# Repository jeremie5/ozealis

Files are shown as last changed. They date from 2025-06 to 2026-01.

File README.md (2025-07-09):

# Ozealis – The $75 Experimental CPAP Simulator

> ⚠️ **NOT A MEDICAL DEVICE.** Experimental use only.  
> **→ See full legal disclaimer below.**

---

WARNING: This project is in pre-prototype / design phase. Nothing is tested yet.
However, you’re welcome to follow, watch, or help out. Contributions and issues are welcome!

---

## 💡 What Is Ozealis?

Ozealis is a fully open-source, modular platform for exploring low-cost, user-driven air-pressure systems. It was created by necessity — for those of us who can’t afford to wait for diagnosis, approval, or overpriced medical devices.

This project is not a product, nor a substitute for professional care. It is a tool for personal experimentation, educational insight, and collaborative innovation.

Because sleep should be safe, and safety should be accessible.

---

## 🔧 Features

- ✅ PTC fuse protection on all power paths
- ✅ Reverse polarity protection via MOSFET (no diode drop)
- ✅ Optional power outage alarm via buzzer and capacitor-based UPS
- ✅ DC5525 input (11V–30V) — compatible with laptop bricks & power stations
- ✅ Differential pressure sensing via physical baffle (not RPM guesswork)
- ✅ Pre/Post humidity & temperature sensing
- ✅ Modular accessory port (USB-A + I²C) for:
  - Heated hose module  
  - Humidifier module  
- ✅ App-controlled via Bluetooth
- ✅ Compatible with $6 standard CPAP hoses
- ✅ No proprietary parts, no DRM
- ✅ Fully 3D-printable enclosure with FDM-optimized geometry

---

## 📷 Photos & Demos

Coming soon. This section will include:

- High-resolution photos  
- Assembly walk-throughs  
- App UI screenshots  
- Demo video showing pressure response & noise levels  

---

## 📦 Getting Started

### 🛠️ Build It Yourself

**Documentation coming soon.** For now, refer to:

- `hardware/` – Schematics, PCB layout, and BoM  
- `firmware/` – ESP32 firmware and config  
- `case/` – STL and STEP files for enclosure (PC + TPU)

Assembly requires:

- Basic soldering skills  
- A 3D printer with 0.4–0.6 mm nozzle  

---

## 📱 App & Data Logging

- Connect via WiFi to view real-time pressure graphs  
- Export logs in JSON or CSV  
- Tune pressure ramp profiles & buzzer thresholds  
- OTA firmware updates planned  

---

## 🛡️ Safety Systems

Ozealis includes multiple built-in protections:

- 🧯 Overcurrent protection on all input/output rails  
- 🔔 Power-loss alarm wakes user with buzzer  
- 🌡️ Thermal cutoff disables output at unsafe temps  
- 💨 Airflow anomaly detection via differential pressure monitoring  

> This level of visibility is **absent in many commercial machines**.

---

## 📄 License

This project is licensed under the **Creative Commons Attribution-NonCommercial 4.0 International (CC BY-NC 4.0)**.

Commercial use (manufacturing, distribution, resale) requires a separate license.  
**Contact:** `team@ozealis.org`

See `LICENSE.md` for full terms.

---

## 🚫 Not a Medical Device

Ozealis is **not approved** by Health Canada, the FDA, or any regulatory agency.  
It is an airflow simulation platform intended for **research and experimental purposes only**.

> No claims are made regarding the treatment, cure, or prevention of sleep apnea or any other condition.

---

## 🤝 Contribute

Pull requests welcome! Areas to contribute:

- App UI & UX polish  
- Log export improvements  
- Pressure tuning curves  
- Testing with accessories (heated hoses, passive humidifiers)  

Fork → improve → PR 💜

---

## 🗺️ Roadmap

- ✅ Full BoM and build guide  
- ✅ App-based tuning UI  
- ✅ Web configurator for real-time control  
- 🎥 YouTube demo + sound comparison  
- 🌍 Translations (FR, EN, ES)

---

**CRITICAL DISCLAIMER — READ BEFORE BUILDING OR USING OZEALIS**  
>   
> 1. **No Medical Device.** Ozealis has **NOT** been reviewed or approved by any
>    regulatory body (FDA, Health Canada, EU MDR, etc.). It is an
>    **experimental air-pressure simulator** provided solely for research,
>    educational and personal *non-commercial* use.  
> 2. **No Professional Advice.** All documentation is for informational
>    purposes only and does **not** constitute medical, engineering, or legal
>    advice. Consult qualified professionals before any practical use.  
> 3. **AS-IS, NO WARRANTIES.** The files, firmware and hardware designs are
>    provided **“AS IS,” WITH ALL FAULTS, WITHOUT WARRANTIES** of any kind,
>    express or implied, including but not limited to merchantability,
>    fitness for a particular purpose and non-infringement.  
> 4. **Assumption of Risk.** You assume **all risks** arising from loading,
>    building, testing or using Ozealis. You are responsible for validating
>    safety, performance and regulatory compliance of any assembly.  
> 5. **Indemnity.** To the maximum extent permitted by law, you **agree to
>    indemnify and hold harmless** Shopiro Ltd. and contributors from any
>    claim, liability or expense (including legal fees) arising from your
>    use, reproduction, or distribution of these materials.  
> 6. **Limitation of Liability.** In no event shall Shopiro Ltd. or
>    contributors be liable for **any indirect, special, incidental or
>    consequential damages** (including personal injury or death) or for an
>    amount exceeding **USD 10**, even if advised of the possibility.  
> 7. **Governing Law & Venue.** These terms are governed by the laws of
>    Québec, Canada, and you consent to exclusive jurisdiction of its courts.  
>
> **By cloning, downloading, or using any part of this repository you
> acknowledge that you have read, understand, and agree to ALL of the above.**

---

Made with urgency, necessity, and care in Canada 🇨🇦  
Because breathing shouldn't require a credit check.

**Ozealis™ is a trademark of Shopiro Ltd.**

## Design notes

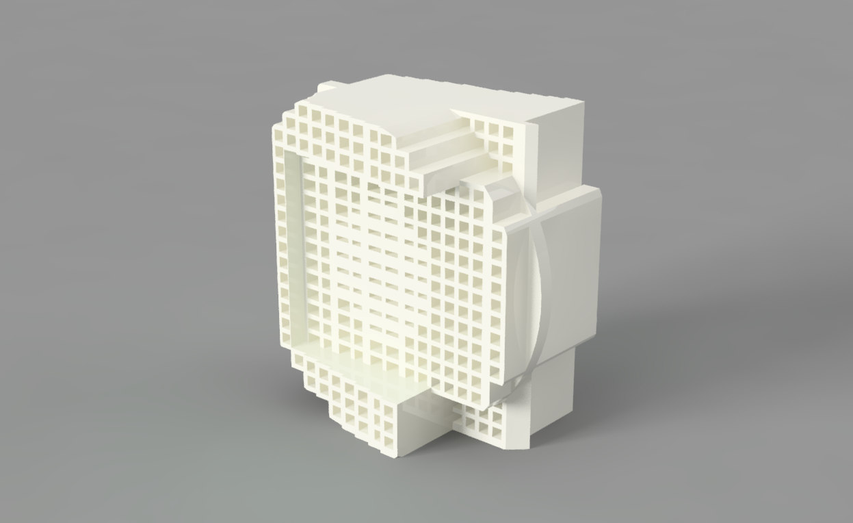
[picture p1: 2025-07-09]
pictures/muffler.png

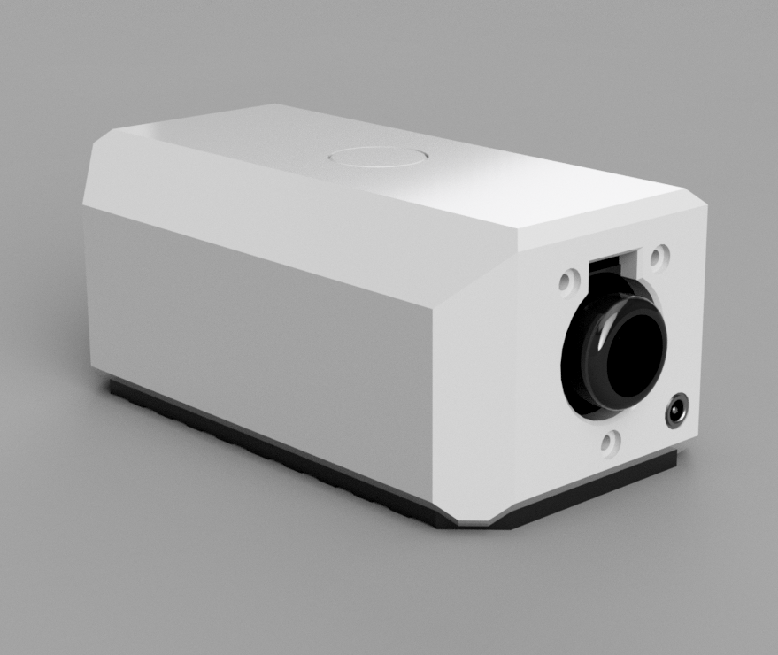
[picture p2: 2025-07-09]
pictures/body.png

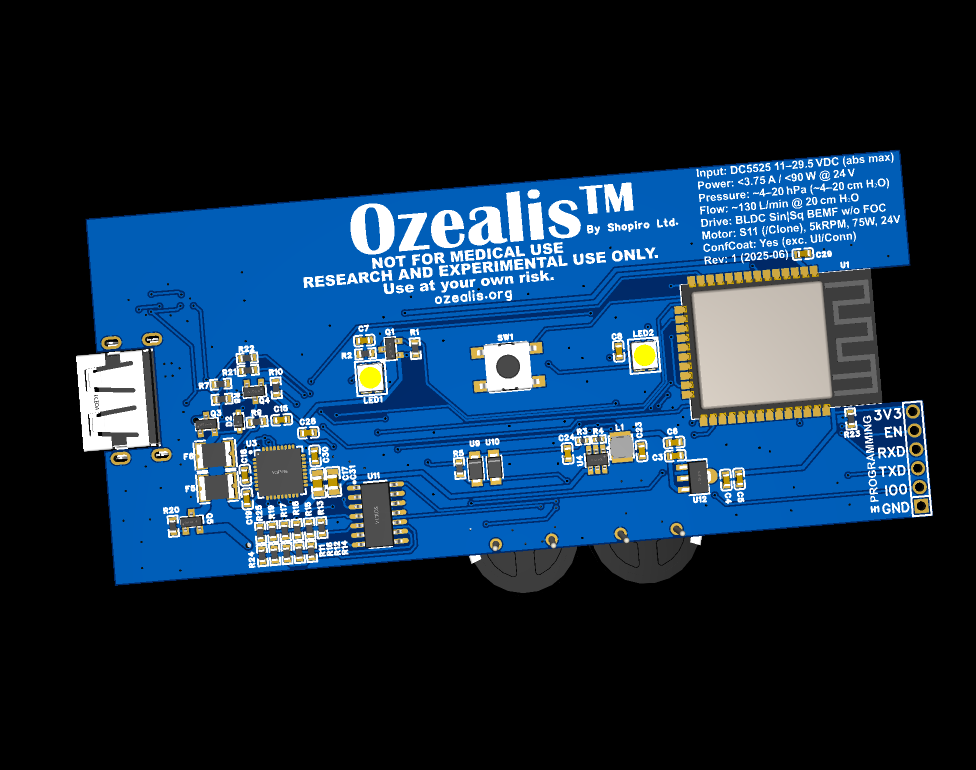
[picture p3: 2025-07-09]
pictures/pcb.png

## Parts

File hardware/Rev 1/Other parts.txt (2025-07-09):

Motor: https://s.click.aliexpress.com/e/_on0QQjY
LPS22HBTR (if unavailable for PCBA): https://s.click.aliexpress.com/e/_omS8MRu
Barrel connector: https://s.click.aliexpress.com/e/_on21ypG

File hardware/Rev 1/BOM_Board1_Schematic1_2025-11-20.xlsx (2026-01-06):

No. | Quantity | Comment | Designator | Footprint | Value | Manufacturer Part | Manufacturer | Supplier Part | Supplier
1 | 1 | 3kHz | BUZZER1 | BUZ-SMD_L9.6-W9.6-LS10.0-R | 3kHz | FUET-9650B-3V | FUET(福声科技) | C391032 | LCSC
2 | 12 | 100nF | C3,C4,C7,C8,C9,C11,C15,C22,C23,C27,C28,C33 | C0603 | 100nF | CC0603KRX7R9BB104 | YAGEO(国巨) | C14663 | LCSC
3 | 5 | 1uF | C5,C6,C10,C12,C29 | C0603 | 1uF | CL10A105KB8NNNC | SAMSUNG(三星) | C15849 | LCSC
4 | 2 | 10uF | C17,C31 | C0805 | 10uF | GRM21BR61H106KE43L | muRata(村田) | C440198 | LCSC
5 | 1 | 10uF | C24 | C0603 | 10uF | TCC0603X5R106M6R3CT | CCTC(三环) | C380318 | LCSC
6 | 2 | 6.3V10000uF | C25,C26 | PolCap_16x25mm | 6.3V10000uF
7 | 1 | 470nF | C30 | C0603 | 470nF | CL10B474KA8NNNC | SAMSUNG(三星) | C1623 | LCSC
8 | 1 | 100uF | C32 | CAP-SMD_BD6.3-L6.6-W6.6-LS7.4-FD | 100uF | RVT100UF35V67RV0034 | KNSCHA(科尼盛) | C2836442 | LCSC
9 | 1 | 10nF | C34 | C0603 | 10nF | 0603B103K500NT | FH(风华) | C57112 | LCSC
10 | 1 | HCZZ0469-2 | CN1 | CONN-SMD_2P-P2.00_HCZZ0469-2 |  | HCZZ0469-2 | HC(虹成电子) | C7433663 | LCSC
11 | 1 | BZT52C10S | D2 | SOD-323_L1.7-W1.3-LS2.6-RD |  | BZT52C10S | 宏嘉诚 | C19077446 | LCSC
12 | 2 | SMD1812-200C-30V | F5,F6 | F1812 |  | SMD1812-200C-30V | BNstar(比诺星) | C2760293 | LCSC
13 | 1 | 2.54-1x6P直针 | H1 | HDR-TH_6P-P2.54-V-M-1 |  | 2.54-1x6P直针 | BOOMELE(博穆精密) | C37208 | LCSC
14 | 1 | 3.3uH | L1 | IND-SMD_L3.0-W3.0_FNR30XXS | 3.3uH | FNR3015S3R3MT | cjiang(长江微电) | C167749 | LCSC
15 | 3 | BLM21PG221SN1D | L2,L3,L4 | L0805 |  | BLM21PG221SN1D | muRata(村田) | C85840 | LCSC
16 | 2 | SK6812MINI-B-012 | LED1,LED2 | LED-SMD_4P-L3.5-W3.5-R-SK6812MINI |  | SK6812MINI-B-012 | 欧思科光电 | C5183448 | LCSC
17 | 1 | BSS138 | Q1 | SOT-23-3_L2.9-W1.3-P1.90-LS2.4-BR-1 |  | BSS138 | KUU | C3015220 | LCSC
18 | 1 | IRLML6344 | Q2 | SOT-23-3_L3.0-W1.7-P0.95-LS2.9-BR |  | IRLML6344 | Hottech(合科泰) | C5364313 | LCSC
19 | 1 | CJ2305 | Q3 | SOT-23-3_L2.9-W1.3-P1.90-LS2.4-BR |  | CJ2305 | CJ(江苏长电/长晶) | C8549 | LCSC
20 | 1 | MMBT3904(RANGE:100-300) | Q4 | SOT-23-3_L2.9-W1.3-P1.90-LS2.4-BR |  | MMBT3904(RANGE:100-300) | CJ(江苏长电/长晶) | C20526 | LCSC
21 | 1 | AO3401A | Q5 | SOT-23_L2.9-W1.3-P1.90-LS2.4-BR |  | AO3401A | UMW(友台半导体) | C347476 | LCSC
22 | 5 | 10kΩ | R1,R2,R11,R12,R13 | R0603 | 10kΩ | RC0603FR-0710KL | YAGEO(国巨) | C98220 | LCSC
23 | 1 | 118kΩ | R3 | R0402 | 118kΩ | RC0402FR-07118KL | YAGEO(国巨) | C295873 | LCSC
24 | 1 | 22.1kΩ | R4 | R0402 | 22.1kΩ | RMC040222.1K1%N | Tyohm(幸亚电阻) | C325588 | LCSC
25 | 1 | 2.2Ω | R5 | R0603 | 2.2Ω | FRC0603J2R2TS | FOJAN(富捷) | C2930032 | LCSC
26 | 17 | 10kΩ | R6,R7,R8,R9,R20,R23,R24,R26,R27,R28,R29,R30,R31,R32,R33,R34,R35 | R0603 | 10kΩ | FRC0603J103 TS | FOJAN(富捷) | C2930027 | LCSC
27 | 1 | 1kΩ | R10 | R0603 | 1kΩ | 0603WAF1001T5E | UNI-ROYAL(厚声) | C21190 | LCSC
28 | 7 | 100kΩ | R14,R15,R16,R17,R18,R19,R25 | R0603 | 100kΩ | 0603WAF1003T5E | UNI-ROYAL(厚声) | C25803 | LCSC
29 | 2 | 100Ω | R21,R22 | R0603 | 100Ω | 0603WAF1000T5E | UNI-ROYAL(厚声) | C22775 | LCSC
30 | 1 | B3FS-1000P | SW1 | KEY-SMD_4P-L6.0-W6.3-P4.50-LS8.0 |  | B3FS-1000P | OMRON(欧姆龙) | C271750 | LCSC
31 | 1 | ESP32-WROOM-32E-N8 | U1 | WIFI-SMD_ESP32-WROOM-32E |  | ESP32-WROOM-32E-N8 | ESPRESSIF(乐鑫) | C701342 | LCSC
32 | 1 | DRV8313RHHR | U3 | VQFN-36_L6.0-W6.0-P0.50-TL-EP |  | DRV8313RHHR | TI(德州仪器) | C165154 | LCSC
33 | 1 | LMR54406DBVR | U4 | SOT-23-6_L2.9-W1.6-P0.95-LS2.8-BR |  | LMR54406DBVR | TI(德州仪器) | C5219316 | LCSC
34 | 2 | LPS22HBTR | U5,U6 | HLGA-10L_LPS22HBTR |  | LPS22HBTR | ST(意法半导体) | C94049 | LCSC
35 | 1 | AHT20 | U7 | SENSOR-SMD_L3.0-W3.0-P1.00-BR |  | AHT20 | 广州奥松 | C2757850 | LCSC
36 | 2 | SD103AWL | U9,U10 | SOD-123FL_L2.8-W1.9-LS3.7-RD |  | SD103AWL | GOODWORK(固得沃克) | C22399516 | LCSC
37 | 1 | LM339 | U11 | SOIC-14_L8.7-W3.9-P1.27-LS6.0-BL |  | LM339 | JSMSEMI(杰盛微) | C5456631 | LCSC
38 | 1 | AMS1117-3.3(XBLW) SOT-89 | U12 | SOT-89-3_L4.5-W2.5-P1.50-LS4.2-BR |  | AMS1117-3.3(XBLW) SOT-89 | XBLW(芯伯乐) | C18723569 | LCSC
39 | 1 | AFB10-S06LCA-00 | U13 | FPC-SMD_6P-P1.00_AFB10-S6LCA-00 |  | AFB10-S06LCA-00 | JS(钜硕电子) | C7499263 | LCSC
40 | 1 | U-A-24DS-W-1 | USB2 | USB-A-SMD_U-A-24DS-W-1. |  | U-A-24DS-W-1 | 韩国韩荣 | C530628 | LCSC

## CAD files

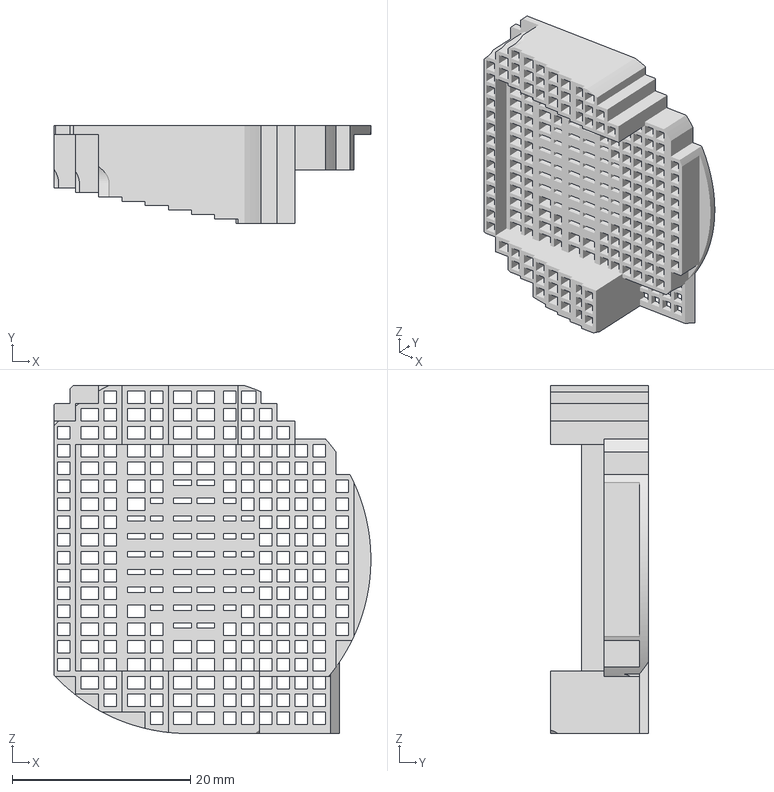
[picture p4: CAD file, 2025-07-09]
hardware/Rev 1/Parts/InletResonator2.3mf
35.5 x 11.0 x 39.0 mm

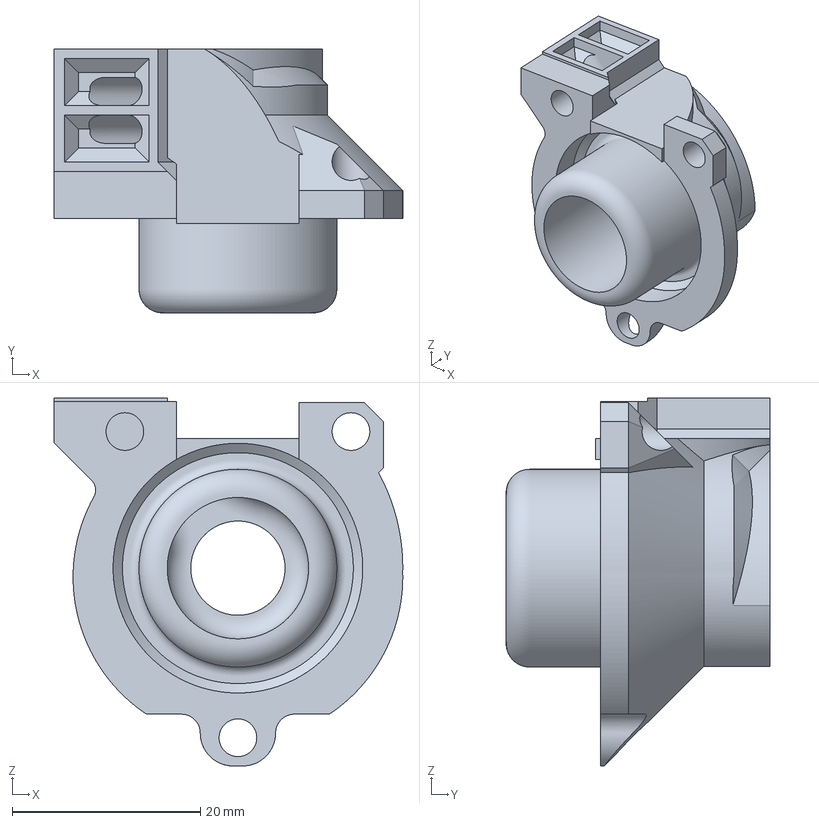
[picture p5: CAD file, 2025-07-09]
hardware/Rev 1/Parts/HoseConnector.3mf
37.0 x 28.0 x 39.1 mm

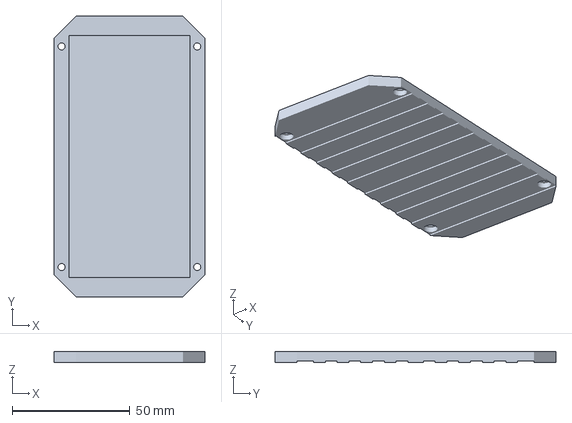
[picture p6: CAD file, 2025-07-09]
hardware/Rev 1/Parts/Base.3mf
64.0 x 119.0 x 4.50 mm

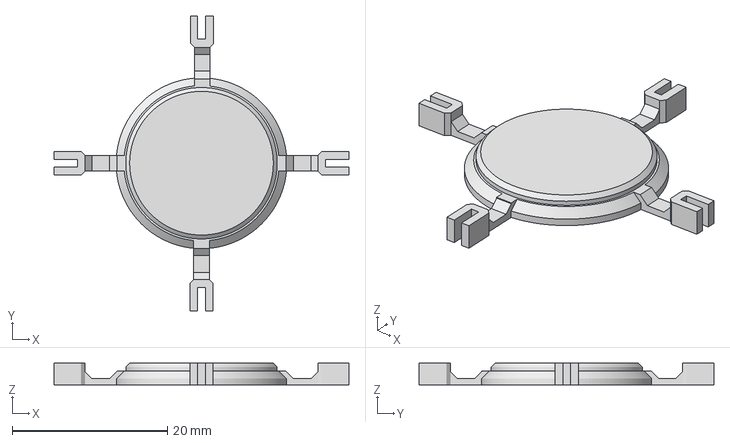
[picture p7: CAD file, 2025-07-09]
hardware/Rev 1/Parts/Button.3mf
38.0 x 37.9 x 2.80 mm

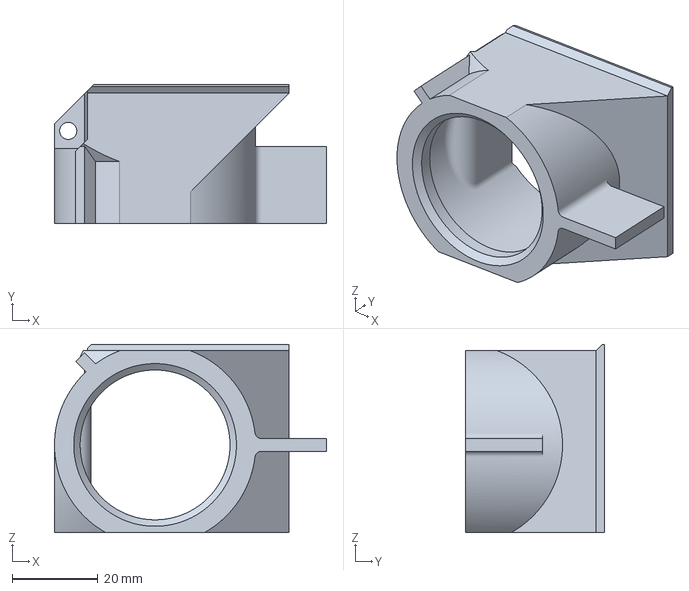
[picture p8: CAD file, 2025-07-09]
hardware/Rev 1/Parts/Inlet.3mf
63.5 x 32.5 x 44.0 mm

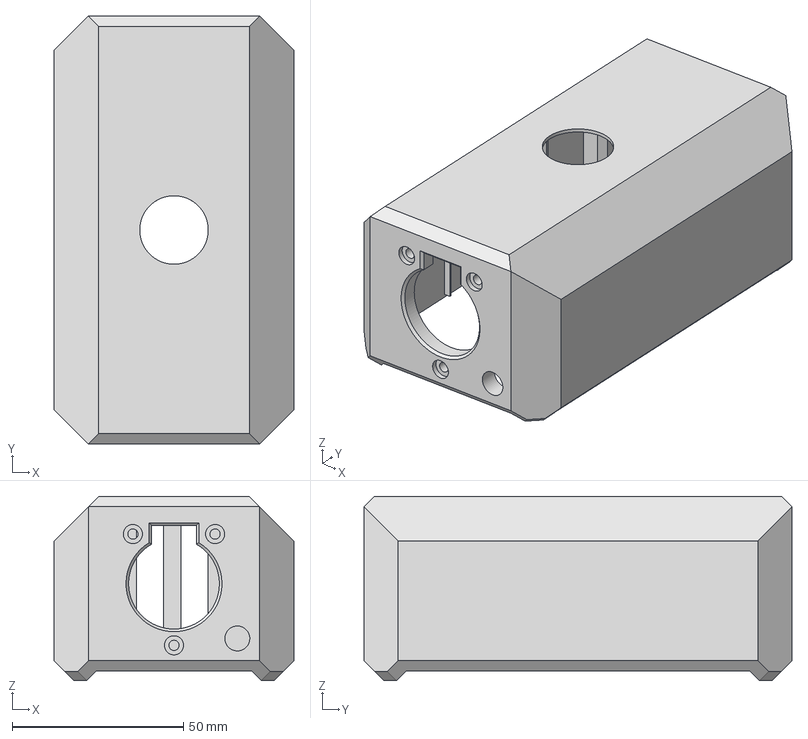
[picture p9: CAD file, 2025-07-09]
hardware/Rev 1/Parts/Body.3mf
70.0 x 125.0 x 53.8 mm

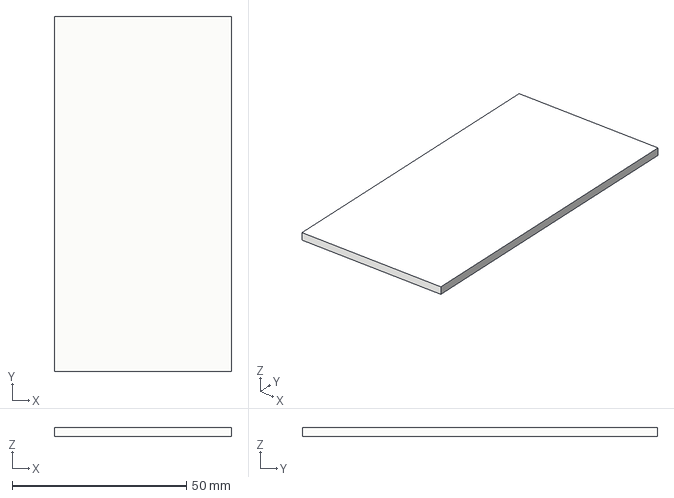
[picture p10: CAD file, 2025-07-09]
hardware/Rev 1/Parts/BaseStiffener.3mf
50.9 x 101.9 x 2.50 mm

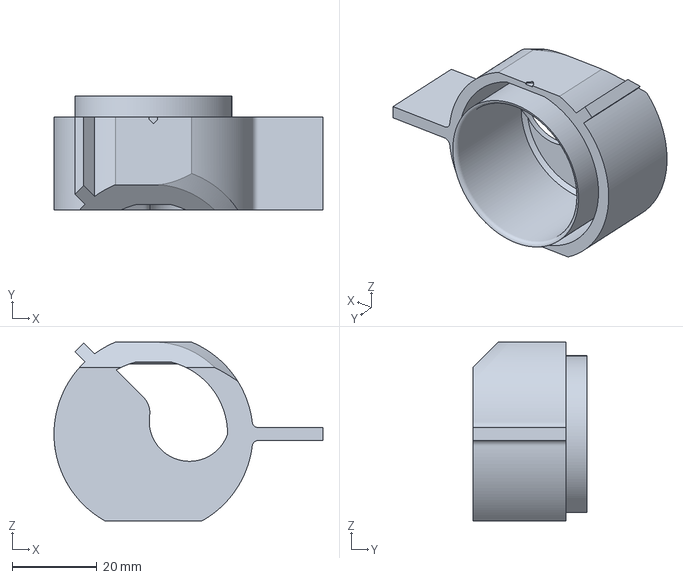
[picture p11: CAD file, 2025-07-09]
hardware/Rev 1/Parts/PumpOutlet.3mf
63.5 x 27.0 x 42.2 mm

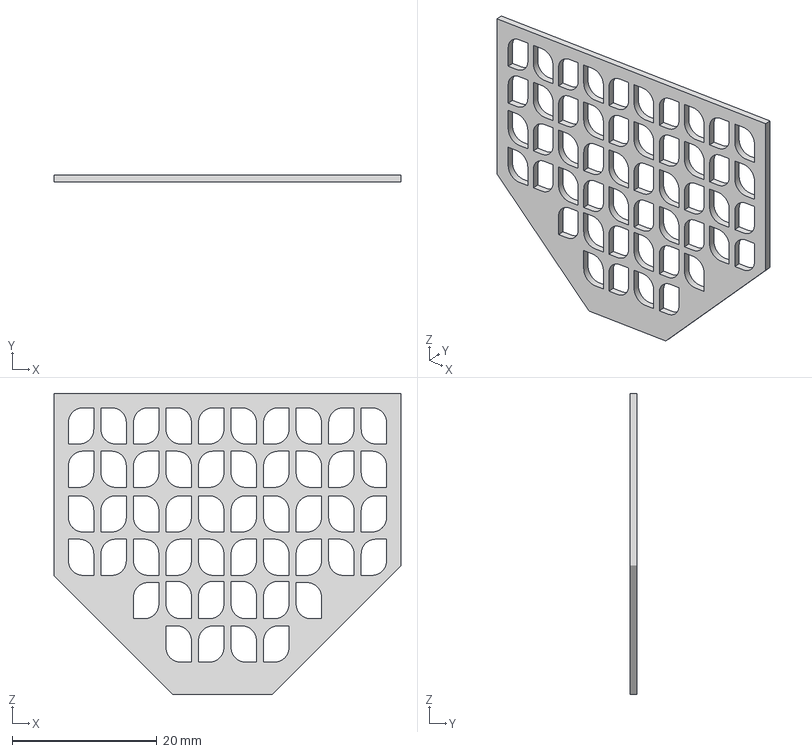
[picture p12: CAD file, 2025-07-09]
hardware/Rev 1/Parts/InletMesh.3mf
48.0 x 1.00 x 41.7 mm

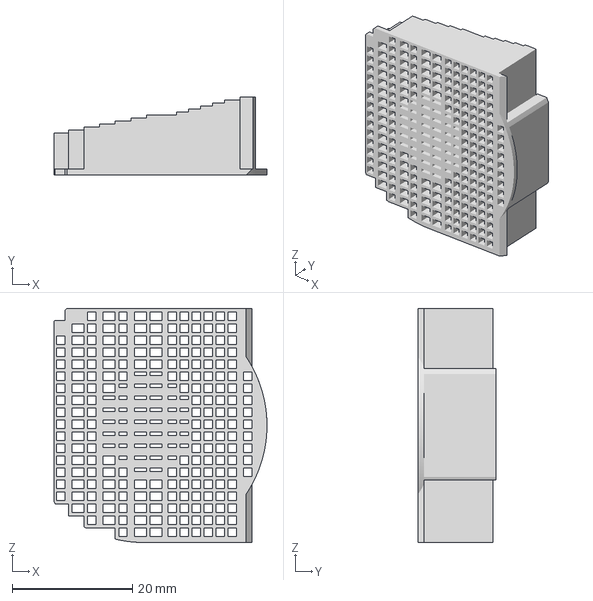
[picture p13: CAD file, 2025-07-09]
hardware/Rev 1/Parts/InletResonator1.3mf
35.5 x 13.0 x 39.0 mm

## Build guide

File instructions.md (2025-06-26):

### 🧽 **Printed Part Finishing (for Breathing Path)**

To ensure hygiene, airflow quality, and durability:

1. 🔥 **Deburr internal air paths**
   Use a lighter or mini butane torch to quickly pass over the interior surface for **1–2 seconds**.
   This melts loose strings and reduces fuzz.
   ⚠️ *Keep the flame moving — do not burn or deform the TPU.*

2. 🖌️ **Seal with aquarium-safe silicone**
   Using a small brush or gloved finger, apply a **thin coat** of **aquarium-safe RTV silicone** (e.g. GE Silicone I, Dow 732) to:

   * The **entire internal breathing path**
   * Any **TPU joints that may flex under airflow**
   * Optionally, the **electronics PCB** to act as a conformal coating replacement

3. ⏳ **Let cure for 24 hours**
   Place parts in a well-ventilated area. Do **not** install or operate before fully cured.

---

### ✅ Notes:

* This ensures **no stringing, no loose microplastics**, and a **cleanable, sterile inner wall**.
* RTV silicones are flexible and adhere to TPU well without cracking.
* Brushing it over the PCB is an effective conformal coating replacement, if avoiding spray-on types.

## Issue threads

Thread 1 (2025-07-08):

Missing files?

dome2048, 2025-07-08:
The "build it yourself" section references several directories for files including STLs, but there are no directories in the code section, just three readme files.

Are these directories located somewhere else?

jeremie5, 2025-07-09:
Thanks for opening this. I just added the files I have right now.
It's still at a pre-prototype, scaffolding stage, but wanted to get it public early.

Contributions are encouraged if you spot bugs or have improvements.
Appreciate you taking the time to look!

dome2048, 2025-07-31:
No problem!

I'll take a look but I am pretty limited in my coding knowledge.

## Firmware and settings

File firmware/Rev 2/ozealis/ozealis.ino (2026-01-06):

// ozealis.ino

/***********************************************************************
*  Ozealis™
*  NOT APPROVED FOR MEDICAL USE. AS-IS, NO WARRANTIES.
*  See README and LICENSE for full legal terms.
***********************************************************************/
#include <string>
#include "led.h"
#include "button.h"
#include "buzzer.h"
#include "motor.h"
#include "ble.h"
#include "autopap.h"
#include "ota_secure.h"
#include "sensor.h"
#include "logic.h"
#include "modules.h"
#include "datalog.h"
#include <esp32-hal-ledc.h>
#include <esp_task_wdt.h>
#include <WiFi.h>

void setup() {
  ESP_ERROR_CHECK(esp_task_wdt_add(nullptr));
  Serial.begin(115200);
  Serial.println("Ozealis - Booting");
  delay(200);
  loadSettings();
  otaSecure_begin();
  setupLED();
  setupBuzzer();
  setupButton();
  setupSensors();
  MotorProfile tune;
  setupMotor(tune);
  initModules();
  PapLimits limits = { 4.0f, 15.0f, 4.0f, 300, true, true, 3 };  // pMin, pMax, Δ, ramp, autoStart, autoStop, EPR
  papBegin(limits);
  dl_init();
  pinMode(ACC_EN, OUTPUT);
  digitalWrite(ACC_EN, LOW);
  buzz(100);
  setLED(255, 0, 255);
}

void loop() {
  esp_task_wdt_reset();
  runMainLogic();
  pollButton();
  ledPairingWaveService();
  motorDebugService();
  static uint32_t lastLog = 0;
  uint32_t now = millis();
  if (now - lastLog >= 2000) {
    lastLog = now;
    float setpoint = papGetSetpointCm();
    float flow = papGetFlowProxy();
    float vin = vinFiltered();
    Serial.print("State: mode=");
    Serial.print(modeName(currentMode));
    Serial.print(" fault=");
    Serial.print(faultName(currentFault));
    Serial.print(" last_fault=");
    Serial.print(faultName(lastFault));
    Serial.print(" setpoint_cm=");
    Serial.print(setpoint, 2);
    Serial.print(" flow_proxy=");
    Serial.print(flow, 2);
    Serial.print(" vin=");
    Serial.print(vin, 2);
    Serial.println(" V");
    motorDumpPins();
  }
  delay(50);
}

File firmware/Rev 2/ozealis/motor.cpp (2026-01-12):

// motor.cpp  DRV8313 EN(PWM) + IN(direction) on ESP32
#include "motor.h"
#include <math.h>
#include <pgmspace.h>
#include <freertos/FreeRTOS.h>
#include <freertos/task.h>
#include <driver/gpio.h>
#include <driver/ledc.h>

/* 8-bit sine LUT 0..255 */
static const uint8_t sineLUT[256] PROGMEM = {
  128,131,134,137,140,143,146,149,152,155,158,162,165,167,170,173,
  176,179,182,185,188,190,193,196,198,201,203,206,208,211,213,215,
  218,220,222,224,226,228,230,232,234,235,237,238,240,241,243,244,
  245,246,248,249,250,250,251,252,253,253,254,254,254,255,255,255,
  255,255,255,255,254,254,254,253,253,252,251,250,250,249,248,246,
  245,244,243,241,240,238,237,235,234,232,230,228,226,224,222,220,
  218,215,213,211,208,206,203,201,198,196,193,190,188,185,182,179,
  176,173,170,167,165,162,158,155,152,149,146,143,140,137,134,131,
  128,124,121,118,115,112,109,106,103,100,97,93,90,88,85,82,
  79,76,73,70,67,65,62,59,57,54,52,49,47,44,42,40,
  37,35,33,31,29,27,25,23,21,20,18,17,15,14,12,11,
  10,9,7,6,5,5,4,3,2,2,1,1,1,0,0,0,
  0,0,0,0,1,1,1,2,2,3,4,5,5,6,7,9,
  10,11,12,14,15,17,18,20,21,23,25,27,29,31,33,35,
  37,40,42,44,47,49,52,54,57,59,62,65,67,70,73,76,
  79,82,85,88,90,93,97,100,103,106,109,112,115,118,121,124
};

/* ===== state machine ===== */
enum MotorState : uint8_t {
  MSTATE_IDLE = 0,
  MSTATE_PREKICK,
  MSTATE_ALIGN,
  MSTATE_RAMP,
  MSTATE_BEMF_WAIT,
  MSTATE_RESCUE,
  MSTATE_RUN
};

static volatile MotorState g_state = MSTATE_IDLE;
static bool    g_state_init       = false;

// align state
static uint8_t  g_align_try   = 0;
static uint8_t  g_align_step  = 0;

// ramp state
static uint16_t g_ramp_i      = 0;
static uint8_t  g_ramp_step   = 0;
static uint32_t g_ramp_next_us = 0;

// BEMF handoff
static uint32_t g_handoff_start_ms = 0;
static uint32_t g_bemf_e0          = 0;

// rescue
static uint32_t g_rescue_start_ms = 0;
static uint8_t  g_rescue_step     = 0;

// control task handle
static TaskHandle_t g_ctrlTask = nullptr;

/* public state */
volatile uint16_t elecAngle = 0;
volatile uint32_t bemfEdges = 0;

/* private state */
static uint8_t amplitude = 0;  // 0..255 magnitude

static uint32_t g_trap_assist_until = 0;

/* LEDC channel and pin maps: 0=U,1=V,2=W */
static const ledc_channel_t CHMAP[3] = { EN_CH_U, EN_CH_V, EN_CH_W };
static const int            ENPIN[3] = { EN_U_PIN, EN_V_PIN, EN_W_PIN };
static const int            INPIN[3] = { IN_U_PIN, IN_V_PIN, IN_W_PIN };

/* profile */
static MotorProfile g_prof;

/* ISR service / IRQ guards */
static bool s_isr_service_installed = false;
static bool s_irq_attached          = false;

/* state flags */
static volatile bool g_running   = false;   // driver awake + EN driving allowed
static volatile bool g_bemfOn    = false;   // logical enable for BEMF ISR gating
static volatile bool g_debug     = false;
static volatile bool g_drvFault = false; /* DRV8313 fault (nFAULT) */

/* commutation helpers */
static TaskHandle_t  g_commTask  = nullptr;
static volatile bool g_commPend  = false;

/* which phase is floating during 6-step (0=U,1=V,2=W) */
static volatile uint8_t g_floatPhase = 2;
static volatile bool    g_trapMode   = false;   // true when using trapStep()

/* BEMF edge debouncers and adaptive ZC */
static volatile uint32_t lastUsU = 0, lastUsV = 0, lastUsW = 0;
static volatile uint32_t lastPeriodUs = 0;      // rough recent ZC period

/* logging config */
static uint16_t      g_log_ms = 200;
static MotorLogFormat g_log_fmt = MLOG_HUMAN;
static uint8_t       g_log_level = 2;
static bool          g_log_enable = false;
static uint32_t      g_log_last = 0;
static uint32_t      g_edges_last = 0;
static uint32_t      g_hold_until = 0;

// ---------------------------------------------------------------
// Forward declarations for internal helpers (static functions)
// ---------------------------------------------------------------

// low-level PWM helpers
static void enWrite(uint8_t ph, uint8_t duty);
static uint32_t enRead(uint8_t ph);

// commutation primitives
static void trapStep(uint8_t step, uint8_t mag);
static void refreshSineVector();

// misc helpers
static void setPwmFreq(uint32_t hz);
static bool in_hold_window();
static int16_t lutSigned(uint8_t idx);
static void drivePolarity(uint8_t ph, bool high_side);

// internal stop
static void motorStopInternal();

/* -------- helpers -------- */
void IRAM_ATTR drvFaultISR() {
  g_drvFault = true;      // set flag, handled next control-task cycle
}

static void motorStopInternal() {
  motorAttachBemf(false);
  g_running = false;
  amplitude = 0;
  enWrite(0,0); enWrite(1,0); enWrite(2,0);
  digitalWrite(IN_U_PIN, LOW);
  digitalWrite(IN_V_PIN, LOW);
  digitalWrite(IN_W_PIN, LOW);
  digitalWrite(NSLEEP_PIN, LOW);
}

static inline void allEN0() {
  enWrite(0,0); enWrite(1,0); enWrite(2,0);
}

static inline uint8_t trapStepToAngle(uint8_t step) {
  // center of each 60° electrical sector (256-angle space)
  static const uint8_t lut[6] = {
    21,   // 30°
    64,   // 90°
    107,  // 150°
    149,  // 210°
    192,  // 270°
    235   // 330°
  };
  return lut[step % 6];
}
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

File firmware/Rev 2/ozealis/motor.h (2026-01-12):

#ifndef MOTOR_H
#define MOTOR_H

#include <Arduino.h>
#include <driver/ledc.h>

/* ---------------------------------------------------------------
   DRV8313 PIN MAP (Ozealis Rev2)
   --------------------------------------------------------------- */
#define EN_U_PIN   19    // PWM EN1
#define EN_V_PIN   18    // PWM EN2
#define EN_W_PIN    5    // PWM EN3

#define IN_U_PIN   12    // direction select 1
#define IN_V_PIN   14    // direction select 2
#define IN_W_PIN   13    // direction select 3

#define NSLEEP_PIN  17    // DRV8313 nSLEEP

#define BEMF_U_IN  32    // LM339 outputs
#define BEMF_V_IN  33
#define BEMF_W_IN  25

#define DRV_FAULT_PIN 26   // nFAULT, active low

/* Select internal pull-ups ONLY for Rev1 bring-up */
#ifndef BEMF_INTERNAL_PULLUP
# define BEMF_INTERNAL_PULLUP 0
#endif

#ifndef DRV8313_IN_HIGH_SELECTS_HIGHSIDE
# define DRV8313_IN_HIGH_SELECTS_HIGHSIDE 0
#endif

/* ---------------------------------------------------------------
   LEDC CONFIG
   --------------------------------------------------------------- */
constexpr uint8_t        PWM_BITS  = 8;
constexpr ledc_mode_t    PWM_MODE  = LEDC_LOW_SPEED_MODE;
constexpr ledc_timer_t   PWM_TIMER = LEDC_TIMER_0;

constexpr ledc_channel_t EN_CH_U = LEDC_CHANNEL_0;
constexpr ledc_channel_t EN_CH_V = LEDC_CHANNEL_1;
constexpr ledc_channel_t EN_CH_W = LEDC_CHANNEL_2;

/* ---------------------------------------------------------------
   PUBLIC MOTOR STATE (minimal + safe to read)
   --------------------------------------------------------------- */
extern volatile uint16_t elecAngle;   // 0..255 electrical angle
extern volatile uint32_t bemfEdges;   // BEMF edge count

/* ---------------------------------------------------------------
   MotorProfile: tuning knobs for startup, ramp, handoff, rescue
   --------------------------------------------------------------- */
struct MotorProfile {
  uint32_t start_pwm_hz     = 8000;     // keep bootstrap happy
  uint32_t run_pwm_hz       = 20000;    // 20k is fine for DRV8313

  uint16_t align_ms         = 120;
  uint8_t  align_mag        = 0;       // was 255 (way too high)

  uint16_t ramp_steps       = 2000;     // less steps while debugging
  uint16_t ramp_dwell_us0   = 2500;     // start slower
  uint16_t ramp_dwell_us1   = 800;      // don't go too fast yet
  uint8_t  ramp_mag0        = 60;       // was 245
  uint8_t  ramp_mag1        = 110;       // was 255

  uint16_t handoff_ms       = 350;
  uint16_t rescue_ms        = 2000;
  uint8_t  rescue_mag       = 50;       // was 255

  uint8_t  trap_floor       = 0;        // IMPORTANT: allow low current
  uint8_t  sine_floor       = 0;
  uint8_t  hold_amp         = 120;
  uint16_t hold_ms          = 1500;

  uint8_t  start_kick_ms    = 0;        // disable kick during bring-up
  uint8_t  multi_align_tries= 3;

  uint16_t min_zc_us_floor  = 80;
  uint16_t min_zc_us_ceil   = 400;
};

/* ---------------------------------------------------------------
   PUBLIC API
   --------------------------------------------------------------- */

// Initialize driver pins, LEDC, tasks
void setupMotor(const MotorProfile& prof = MotorProfile{});

// Non-blocking start (handled by control task)
void startMotor();

// Fully stop and sleep driver
void stopMotor();

// Set target amplitude in sine-commutation mode
void setMotorAmplitude(uint8_t amp);
uint8_t motorGetAmplitude();

// Running = driver awake AND motor not idle (may still be ramping)
bool motorIsRunning();

// Starting = in PREKICK / ALIGN / RAMP / BEMF_WAIT / RESCUE
bool motorIsStarting();

// True if rotor has stable BEMF feedback
bool motorHasLock();

// Attach/detach zero-cross interrupts manually (rare)
void motorAttachBemf(bool on);

/* ---------------------------------------------------------------
   Debug / diagnostics
   --------------------------------------------------------------- */

enum MotorLogFormat : uint8_t { MLOG_HUMAN = 0, MLOG_CSV = 1 };

void motorEnableDebug(bool on);
void motorLogConfigure(bool enable,
                       uint16_t period_ms = 200,
                       MotorLogFormat fmt = MLOG_HUMAN,
                       uint8_t level      = 2);

void motorDebugService();     // call from main loop
void motorLogOnce();          // single snapshot
void motorDumpPins();         // print instantaneous pin states
void motorForceStep(uint8_t step, uint8_t mag, uint16_t ms);

/* ---------------------------------------------------------------
   Compatibility
   --------------------------------------------------------------- */
inline void restartMotor() { startMotor(); }

/* drive enable/disable used by higher-level PAP logic */
inline void motorSetDriveEnabled(bool on) {
  if (on) startMotor();
  else    stopMotor();
}

/* trap keepalive is now a no-op (commutation fully task-based) */
inline void motorTrapKeepalive(uint16_t, uint8_t) {}

#endif  // MOTOR_H

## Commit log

2025-07-09 Pre-prototype project files
    [Base.3mf, BaseStiffener.3mf, Body.3mf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]
2026-01-06 Rev 2 software
    [BOM_Board1_Schematic1_2025-11-20.xlsx]
